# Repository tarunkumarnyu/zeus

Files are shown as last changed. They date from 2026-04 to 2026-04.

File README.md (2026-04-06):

# ZEUS — Autonomous Payload-Delivery Hexacopter






> **Note —** This is an **aero design project**, not a software repository. There is no source code: the work covers conceptual design, weight & thrust budgeting, propulsion sizing, structural analysis, CAD, and the build itself. This repo holds the SolidWorks assets, the system architecture, and the engineering drawing produced for the design report.

A custom-built hexacopter for autonomous waypoint missions with a 900 g servo-actuated payload drop. Designed and built by **Team ASRL** at SRM Institute of Science and Technology for **Rotorcraft Design Challenge — Nitte 2024**, the annual collegiate aero-design competition organised by **NMAM Institute of Technology** under the **SAE India Aerospace** banner (Team No. ROTOR2407).

## Contents

- [Conceptual Design](#conceptual-design)
- [Weight Estimation](#weight-estimation)
- [Thrust Estimation](#thrust-estimation)
- [Propulsion System](#propulsion-system)
- [UAV Configuration Selection](#uav-configuration-selection)
- [Wheelbase & Sizing](#wheelbase--sizing)
- [Power & Endurance](#power--endurance)
- [Design Iterations](#design-iterations)
- [Material Selection](#material-selection)
- [Subsystem Selection](#subsystem-selection)
- [System Architecture](#system-architecture)
- [CG, Topology Optimisation & FEA](#cg-topology-optimisation--fea)
- [Landing Gear](#landing-gear)
- [Autonomous Mission](#autonomous-mission)
- [Payload Drop Mechanism](#payload-drop-mechanism)
- [Weight Breakdown](#weight-breakdown)
- [Bill of Materials](#bill-of-materials)
- [Engineering Drawing](#engineering-drawing)

## Conceptual Design

<p align="center">
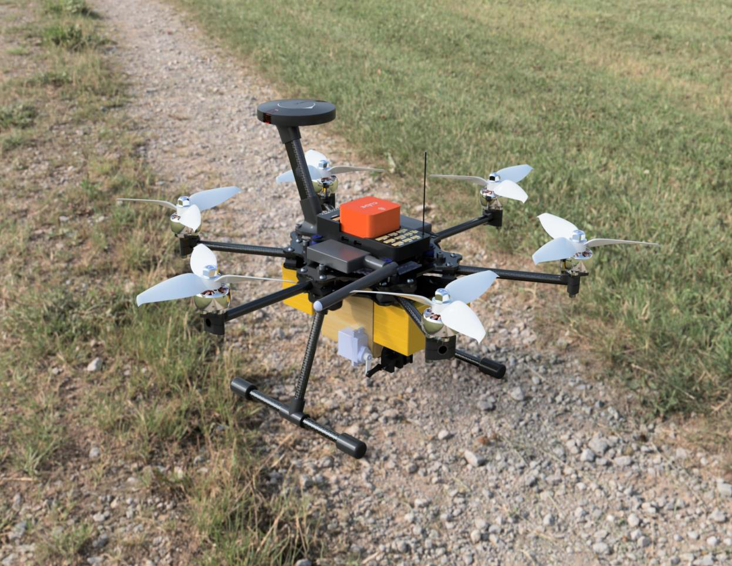
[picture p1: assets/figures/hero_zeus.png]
ZEUS hexacopter — high level view
  
  <br/><em>Fig. 1 — High level view of the assembled ZEUS platform</em>
</p>

ZEUS is a 2 kg-class hexacopter engineered for autonomous flight with precision payload delivery. The platform integrates a topology-optimised carbon-fiber airframe, a Pixhawk-based avionics stack, and a torque-balanced double-door payload bay. The full mission — take-off, GPS waypoint navigation, target loiter, payload release, return-to-home — is planned in Mission Planner and executed autonomously by the flight controller.

The hexacopter configuration was chosen over a quadcopter for the 50% thrust margin and motor-failure tolerance, and over an octocopter to keep weight and current draw low enough to fit a 5+ minute flight envelope on a single 6S battery pack.

## Weight Estimation

Take-off weight is estimated using the standard rotorcraft formula:

```
Wto = Woe + Wpl + Wf
```

| Term | Description | Value |
|---|---|---|
| `Woe` | Operational empty weight (frame + electronics, no battery) | 671 g |
| `Wpl` | Payload weight (mission requirement) | 900 g |
| `Wf`  | "Fuel" weight — battery pack | 480 g |
| **`Wto`** | **Total take-off weight** | **2051 g** |

Preliminary estimate during early design was 2120 g; the final figure of **2051 g** reflects a 69 g reduction achieved through frame iteration and topology optimisation.

## Thrust Estimation

```
Thrust required for take-off = Wto + 20% safety margin
                             = 2051 + 410.2 = 2461.2 g

Thrust per motor             = 2461.2 / 6 = 410.2 g
```

A 20% margin above hover ensures sufficient authority for climb, manoeuvring, and gust rejection. The selected motor/prop combination delivers >430 g per motor at the operating voltage, clearing the requirement.

## Propulsion System

An electric propulsion system was chosen for low noise, zero local emissions, and compatibility with the small-frame BLDC ecosystem.

| Item | Selection | Rationale |
|---|---|---|
| Motors | **Emax ECO II 2306, 1700 KV BLDC** | Meets 410 g/motor static thrust target; high durability; low electrical noise |
| Propellers | **5″ tri-blade** | Best stability/efficiency trade for the wheelbase; tri-blade preferred over bi-blade for thrust at this disc loading |
| Battery | **2× 1300 mAh 6S LiPo (parallel)** | 2600 mAh, 25.2 V nominal, 100C discharge — supports peak current and 5 min endurance |

<table align="center">
<tr>
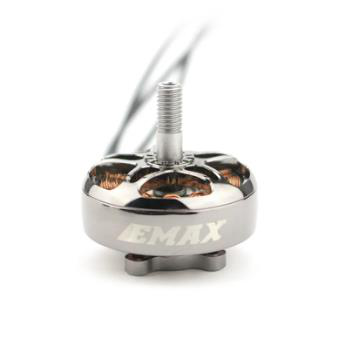
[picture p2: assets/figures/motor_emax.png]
<td align="center"><br/><em>Fig. 2 — Emax ECO II 2306 BLDC motor</em></td>
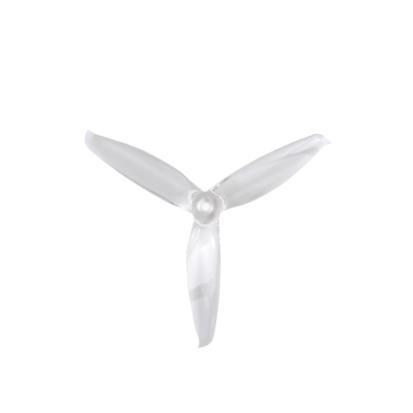
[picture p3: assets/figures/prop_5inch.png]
<td align="center"><br/><em>Fig. 3 — 5″ tri-blade propeller</em></td>
</tr>
</table>

## UAV Configuration Selection

| Configuration | Weight | Endurance | Stability | Thrust |
|---|---|---|---|---|
| Quadcopter | Low | High | Low | Low |
| **Hexacopter** | **Medium** | **Medium** | **High** | **High** |
| Octocopter | High | Low | High | High |

**Why hexacopter:** Two extra motors over a quadcopter increase total static thrust by 50%, reduce per-motor load and current draw, and provide tolerance to a single-motor failure (the controller can compensate by re-mixing the remaining five). An octocopter would add weight and current draw without a meaningful payload-fraction gain at this scale.

<table align="center">
<tr>
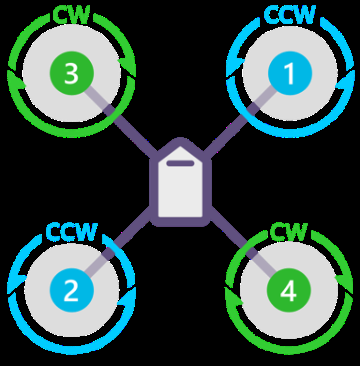
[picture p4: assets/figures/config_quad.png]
<td align="center"><br/><em>Fig. 4 — X Quad</em></td>
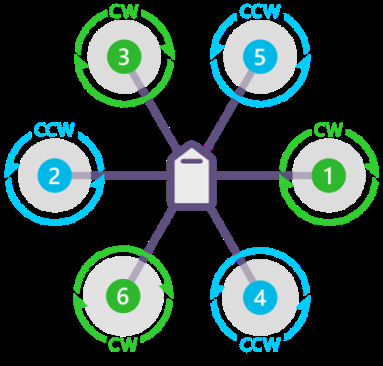
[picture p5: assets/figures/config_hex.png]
<td align="center"><br/><em>Fig. 5 — X Hexa (selected)</em></td>
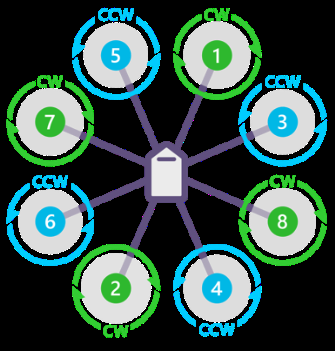
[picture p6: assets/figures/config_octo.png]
<td align="center"><br/><em>Fig. 6 — X Octo</em></td>
</tr>
</table>

## Wheelbase & Sizing

- **Horizontal wheelbase** (centre to centre, adjacent motor mount): **168 mm**
- **Diagonal wheelbase** (motor to opposite motor): **335 mm**
- **Propeller clearance**: **40 mm** between adjacent prop tips to prevent collisions
- **Overall envelope**: L = 335.5 mm, W = 290.5 mm, H = 237.6 mm
- **Landing gear height**: 100 mm — sufficient ground clearance for payload bay attachment without ground strike

All electronics live on the top plate for CG balance and easy field access. The two batteries sit symmetrically front and rear at datum distances of 89 mm and 199 mm so the loaded CG stays within ±5 mm of the geometric centre.

<table align="center">
<tr>
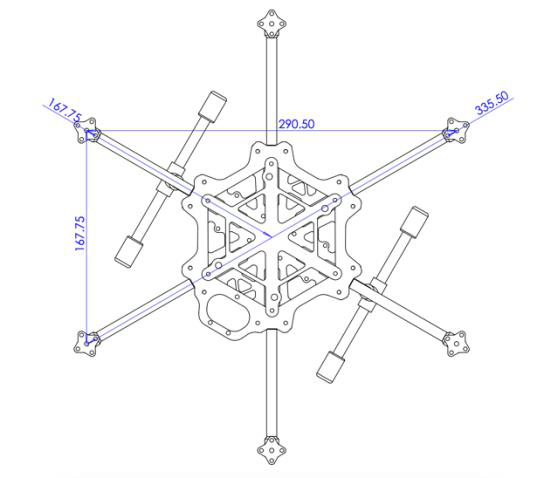
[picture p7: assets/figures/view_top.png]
<td align="center"><br/><em>Fig. 7 — Wheelbase &amp; top view dimensions</em></td>
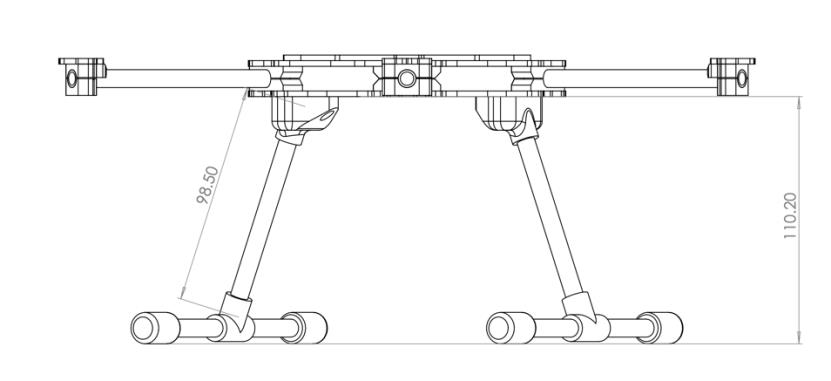
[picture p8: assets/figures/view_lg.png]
<td align="center"><br/><em>Fig. 8 — Front view with landing-gear clearance</em></td>
</tr>
</table>

## Power & Endurance

**Power required (hover):**

```
Hover current per motor : 4 A
Bus voltage             : 25.2 V
Power per motor         : 100.8 W
Power for 6 motors      : 604.8 W
Avionics overhead       : ~20 W
Total hover power       : 625 W
```

**Power available:**

```
Battery energy = 2.6 Ah × 25.2 V = 65.52 Wh
Energy for 5 min hover = 625 W × (5/60) h = 51.875 Wh   ✓ (margin of 13.6 Wh)
```

**Endurance:**

```
Avg amp draw = (Wto · 294.811 W/kg) / 25.2 V
             = (2.051 · 294.811) / 25.2
             = 23.99 A

Flight time @ 80% safe discharge = (2.6 · 0.8) / 23.99
                                 = 0.0867 h
                                 ≈ 5.20 min
```

The 80% discharge limit is enforced to preserve LiPo cell health.

## Design Iterations

The frame went through three major iterations, each driven by FEA results and weight measurements from the previous build.

**Iteration 1 — Strength-first.**
Designed to withstand extreme combined loads. Base plate topology-optimised with 10% material removal. 15 mm CF round tubes used as arms. Motor mount plates fixed with two dual-arm attachments per arm for maximum stiffness. **Drawback:** excessive weight from the heavy tubes and large fastener count.

**Iteration 2 — Weight reduction.**
Aggressive topology optimisation on every plate. 15 mm CF round tubes replaced with **pultruded CF square tubes** (lighter, easier to clamp). Motor mount bolts cut from **9 to 2 per motor**. Significant weight savings, but the square pultruded tubes were not as strong as desired in bending.

**Final Iteration — Stability + strength.**
Distance between base and top plate **minimised** to maximise frame torsional stiffness. Pultruded square tubes replaced with **8 mm circular 3K roll-wrapped CF tubes** — lighter per arm and significantly stronger than pultruded due to the continuous fibre wrap. This is the version that flew.

<table align="center">
<tr>
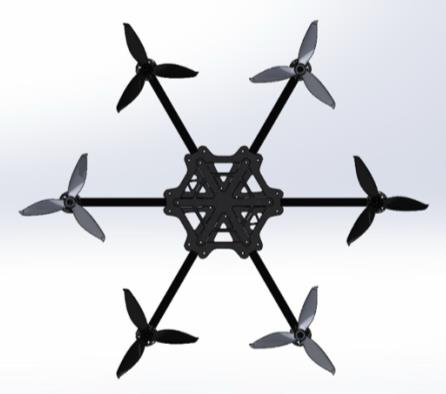
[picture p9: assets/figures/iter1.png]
<td align="center"><br/><em>Fig. 9 — Iteration 1 (strength-first)</em></td>
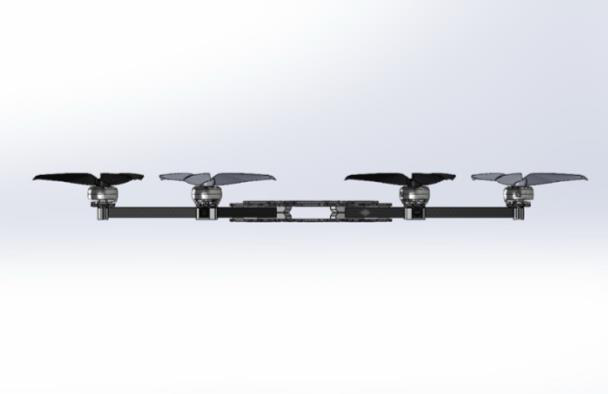
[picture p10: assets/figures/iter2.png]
<td align="center"><br/><em>Fig. 10 — Iteration 2 (weight reduction)</em></td>
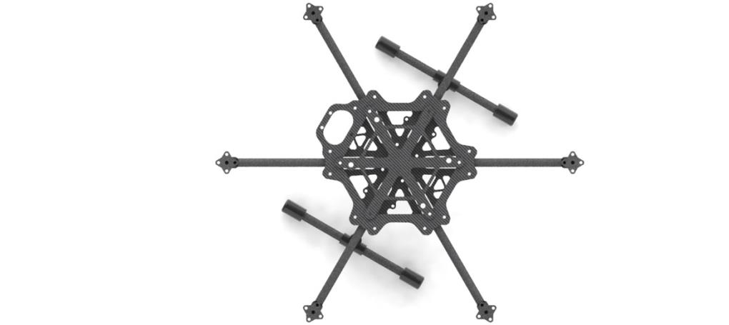
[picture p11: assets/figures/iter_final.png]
<td align="center"><br/><em>Fig. 11 — Final iteration</em></td>
</tr>
</table>

## Material Selection

**Carbon-Fiber Plate (frame plates).** High strength-to-weight ratio carries flight loads with minimal mass. Rigid under combined thrust and gust loads, preventing flex that would otherwise corrupt IMU readings.

**3K Roll-Wrapped CF Tube (arms).** Continuous-fibre wrapped tubes selected over pultruded because the fibre orientation gives excellent bending and torsional stiffness — essential for arms that carry the full thrust moment of one motor at the tip.

**PLA+ (3D-printed attachments).** All complex geometric attachments — motor mounts, arm clamps, payload bay parts, landing gear feet — manufactured via FDM 3D printing in PLA+. Higher toughness and inter-layer adhesion than standard PLA, no warping issues during long prints.

<p align="center">
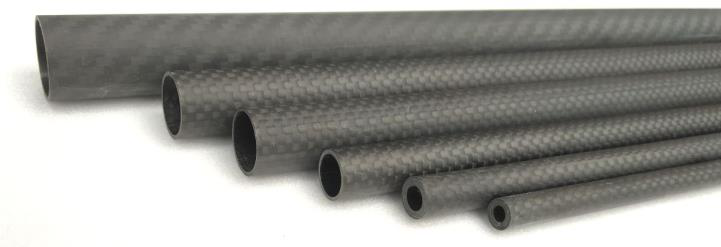
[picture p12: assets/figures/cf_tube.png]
3K roll-wrapped CF tubes
  
  <br/><em>Fig. 12 — 3K roll-wrapped carbon-fiber tube stock used for the arms</em>
</p>

## Subsystem Selection

### Telemetry
**Holybro SiK Telemetry Module.** MAVLink-compatible, plug-and-play with Mission Planner. 433 MHz, 500 mW output. Used for live mission upload, parameter tuning in the field, and downlink of GPS / battery / attitude.

<p align="center">
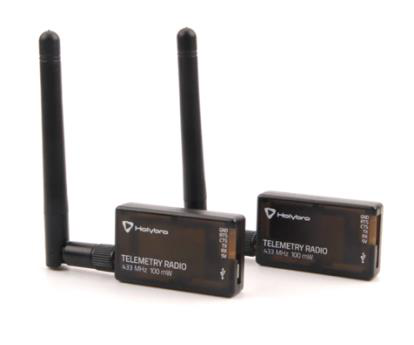
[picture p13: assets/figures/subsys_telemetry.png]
Holybro SiK telemetry module
  
  <br/><em>Fig. 13 — Holybro telemetry SiK module pair</em>
</p>

### Radio link
**TBS Tango 2 Pro + Crossfire receiver.** Crossfire protocol on 915 MHz, 4 km range, 8 channels — 4 for axes (roll, pitch, yaw, throttle) and 4 for flight mode switching, payload trigger, and arm/disarm.

<p align="center">
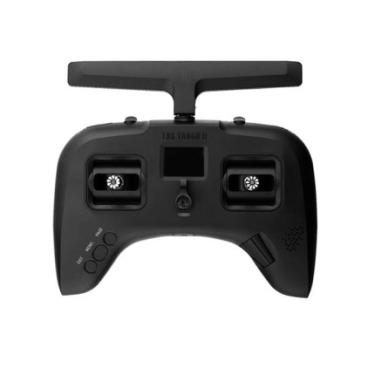
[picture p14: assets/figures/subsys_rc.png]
TBS Tango 2 Pro transmitter
  
  <br/><em>Fig. 14 — TBS Tango 2 Pro transmitter</em>
</p>

### Flight controller
**Pixhawk Cube Orange.**
- 3 sets of IMU sensors with redundancy voting
- 2 of the 3 IMUs are vibration-isolated for accurate state estimation
- Onboard heater resistors hold IMU temperature stable to reduce gyro bias drift
- Runs ArduPilot with the standard hexacopter mixer

<p align="center">
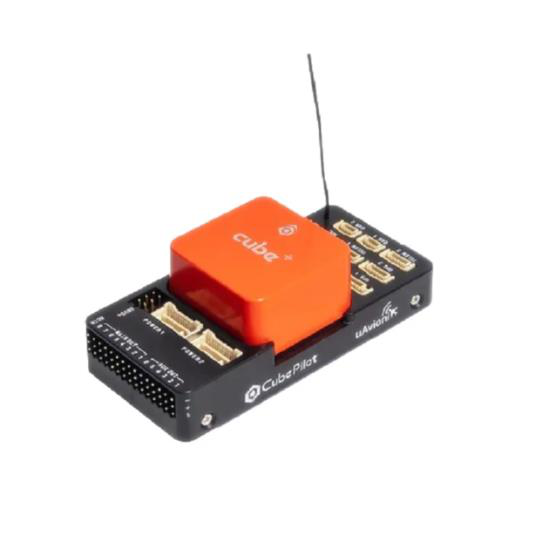
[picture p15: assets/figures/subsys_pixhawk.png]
Pixhawk Cube Orange
  
  <br/><em>Fig. 15 — Pixhawk Cube Orange flight controller</em>
</p>

### GPS / INS
**Here3 GPS.** Full inertial navigation suite — gyroscope, accelerometer, magnetometer, barometer — combined with GNSS receiver. RTK positioning data is fused with IMU/baro in the Pixhawk's Extended Kalman Filter (EKF) for sub-metre position hold.

<p align="center">
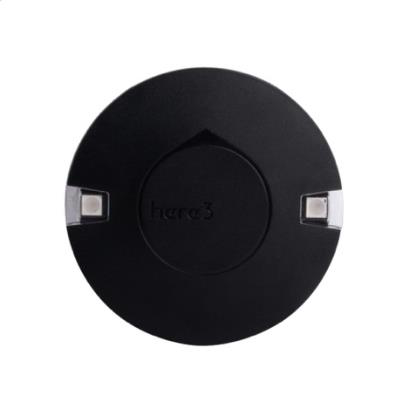
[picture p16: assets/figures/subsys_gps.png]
Here3 GPS
  
  <br/><em>Fig. 16 — Here3 RTK GPS / INS unit</em>
</p>

### Electronic Speed Controllers
Two **4-in-1 ESC modules** chosen instead of six individual ESCs to save weight, wiring complexity, and assembly time. Specifications:
- 3S–6S input range
- 50 A continuous per channel
- 1000 µF bulk capacitor per ESC to filter PWM-induced current ripple at the battery bus

<table align="center">
<tr>
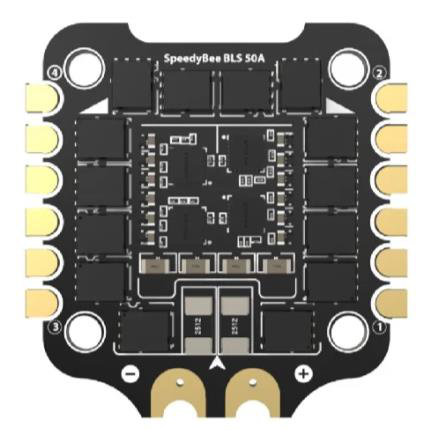
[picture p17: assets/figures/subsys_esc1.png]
<td align="center"><br/><em>Fig. 17 — Speedybee 50 A 4-in-1 ESC</em></td>
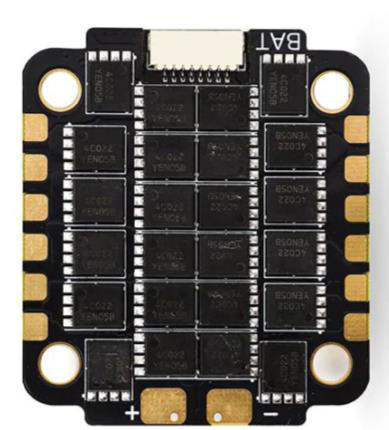
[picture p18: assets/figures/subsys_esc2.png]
<td align="center"><br/><em>Fig. 18 — HGLRC 50 A 4-in-1 ESC</em></td>
</tr>
</table>

## System Architecture

<p align="center">
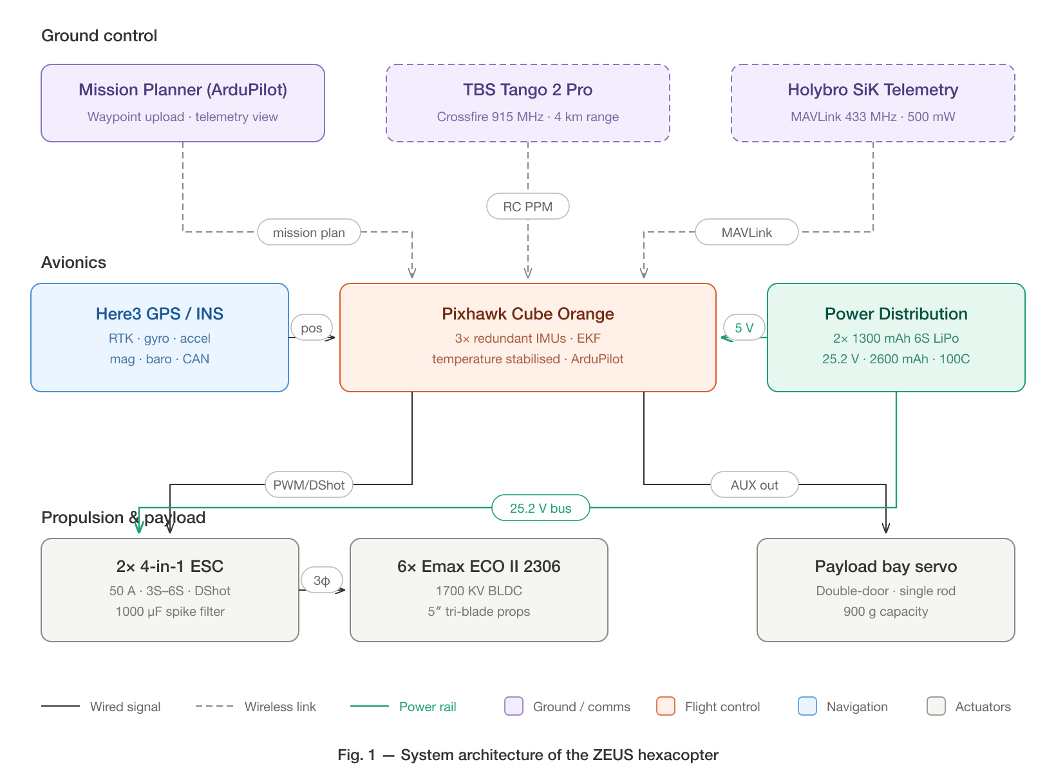
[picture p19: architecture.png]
ZEUS System Architecture
  
</p>

## CG, Topology Optimisation & FEA

**CG estimation.** Two battery slots are placed symmetrically front and back of the frame. The loaded CG falls almost exactly at the midpoint of the two battery slots and slightly above the geometric origin of the airframe — close enough to the thrust centroid that no asymmetric trim is required.

<p align="center">
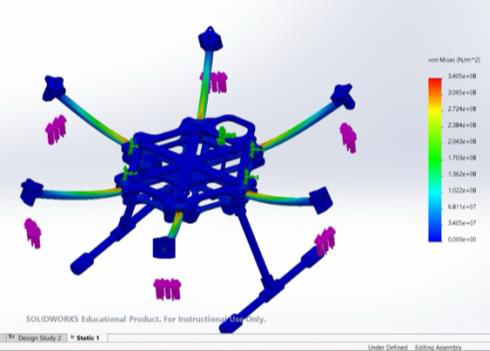
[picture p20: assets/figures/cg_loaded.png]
Loaded CG render
  
  <br/><em>Fig. 20 — Loaded CG: ZEUS with payload bay attached, front view</em>
</p>

**Topology optimisation.** Two FEA load cases were run on the base plate:
- *Method 1* — fixtures at the arm mountings, force applied at the plate centre (simulating a payload load on a hovering frame)
- *Method 2* — centre of plate fixed, force applied at the arm mountings (simulating thrust loads in flight)

The final geometry is the **intersection** of the load paths from both methods — material is removed only where neither case carries stress.

<table align="center">
<tr>
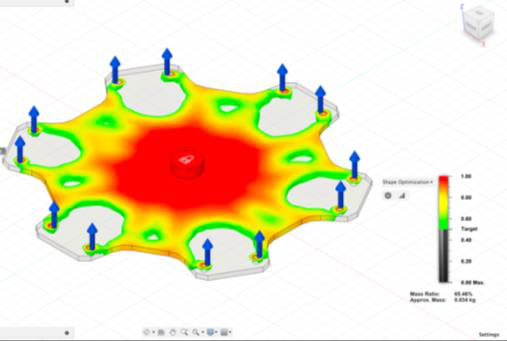
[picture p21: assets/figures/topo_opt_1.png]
<td align="center"><br/><em>Fig. 21 — Topology optimisation, Method 1</em></td>
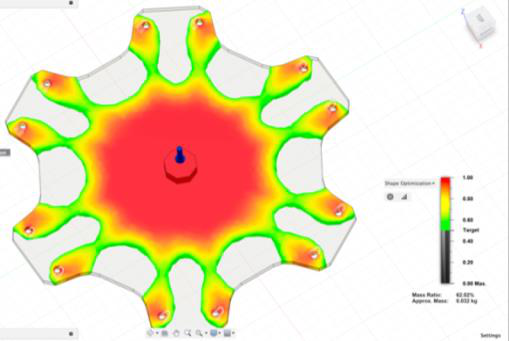
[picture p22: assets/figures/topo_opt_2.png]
<td align="center"><br/><em>Fig. 22 — Topology optimisation, Method 2</em></td>
</tr>
</table>

**Static structural analysis.** Whole-frame FEA was run under the maximum combined static thrust of all six motors (~120 N) to validate plate integrity under the worst-case flight load. Maximum von Mises stress stayed well below the CF laminate's yield, with peak displacement at the plate corners.

<table align="center">
<tr>
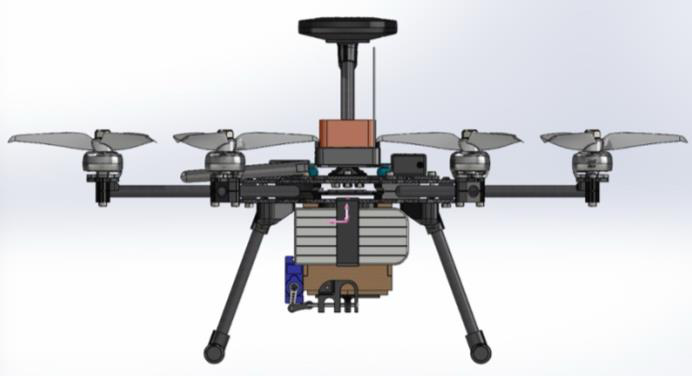
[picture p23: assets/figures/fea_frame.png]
<td align="center"><br/><em>Fig. 23 — Plate-level static FEA</em></td>
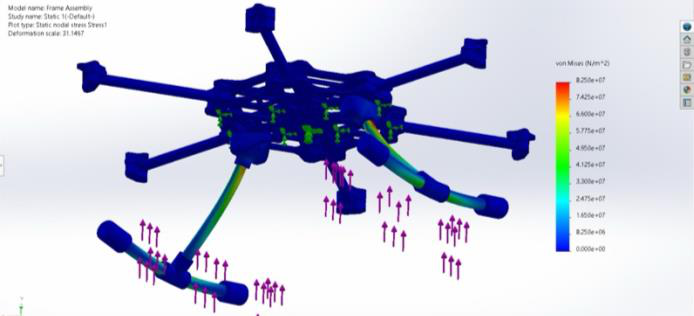
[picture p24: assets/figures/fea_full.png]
<td align="center"><br/><em>Fig. 24 — Full-frame static FEA under 120 N thrust</em></td>
</tr>
</table>

## Landing Gear

A **skid-type** landing gear was selected over wheeled or fixed-leg alternatives for maximum stability and ground contact area. The gear was designed in SolidWorks and run through FEA under the worst-case landing impact load to size the wall thickness. Complex skid geometry is **3D-printed in PLA+** with internal infill tuned to absorb impact energy without permanent deformation.

The 100 mm clearance is the minimum that lets the payload bay clear the ground when the bay doors are open.

<p align="center">
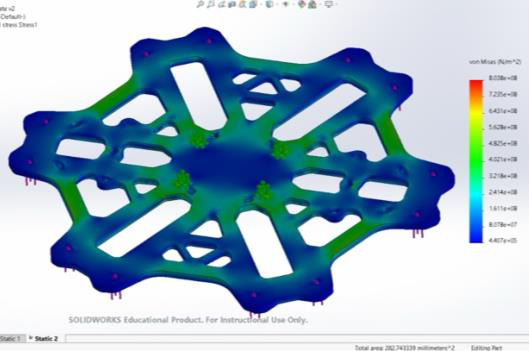
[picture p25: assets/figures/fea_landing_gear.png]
Landing gear FEA
  
  <br/><em>Fig. 25 — Landing gear FEA under landing impact load</em>
</p>

## Autonomous Mission

Mission planning is done in **Mission Planner (ArduPilot)**. The pilot defines the home position, take-off altitude, GPS waypoint sequence, and return-to-home behaviour; the full plan is uploaded to the Pixhawk over the 433 MHz MAVLink telemetry link before flight.

```
Arm + Take-off  →  Waypoint nav  →  Target loiter  →  Payload drop  →  Return to home
```

**Phase 1 — Take-off.** Take-off altitude is set to 5 m in the ground station. The Pixhawk arms, spools the motors, and climbs vertically to the set altitude under altitude-hold.

**Phase 2 — Waypoint Navigation.** The drone follows the planned GPS waypoint path autonomously between home and the target area. The EKF fuses RTK GPS with IMU and baro to maintain position lock.

**Phase 3 — Target Loiter & Drop.** The drone holds station above the target while the payload servo is triggered (via an AUX channel from the FC).

**Phase 4 — Return to Home.** On mission completion, the drone autonomously returns to the home position and performs a controlled descent.

<table align="center">
<tr>
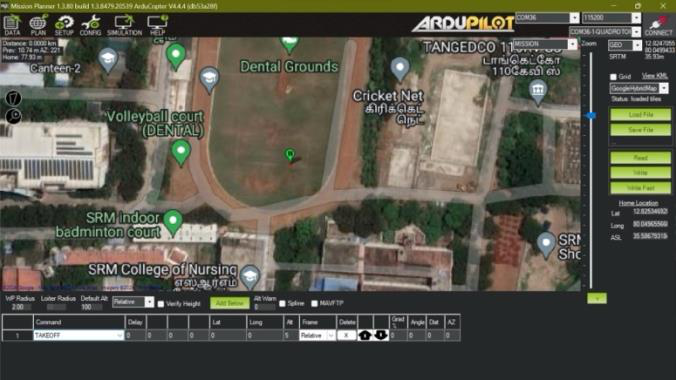
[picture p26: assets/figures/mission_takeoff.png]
<td align="center"><br/><em>Fig. 26 — Mission Planner: take-off altitude set</em></td>
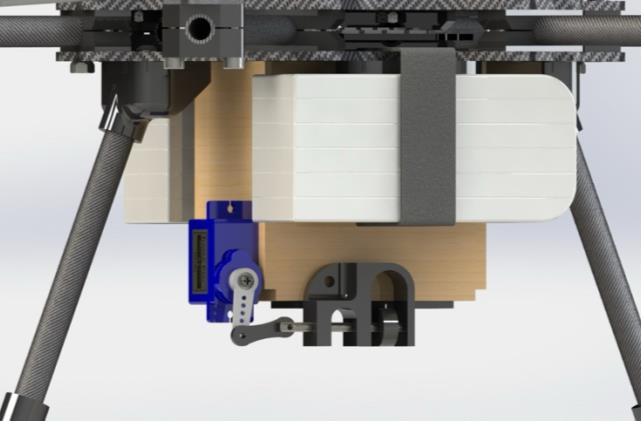
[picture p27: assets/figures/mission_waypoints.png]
<td align="center"><br/><em>Fig. 27 — Mission Planner: waypoint plan</em></td>
</tr>
</table>

## Payload Drop Mechanism

The payload bay sits below the frame on a **double-door release mechanism** actuated by a single servo. Key design choices:

- **Double-door geometry** — two symmetric doors open simultaneously instead of a single side door. This cancels the reaction torque at release so the drop does not perturb the airframe's attitude.
- **Single-rod lock** — a single sliding rod, driven by one servo, latches both doors. This minimises the part count and the failure modes.
- **900 g rated capacity** — sized to the competition payload spec.
- **Mounted below the airframe** on the centreline so the CG shift after release is purely vertical.

<table align="center">
<tr>
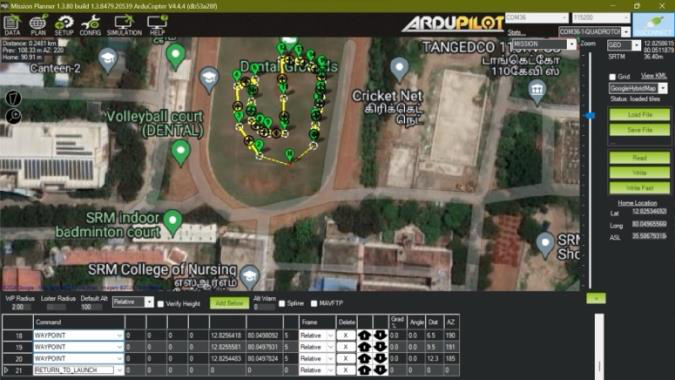
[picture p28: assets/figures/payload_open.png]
<td align="center"><br/><em>Fig. 28 — Payload bay (doors closed, latched)</em></td>
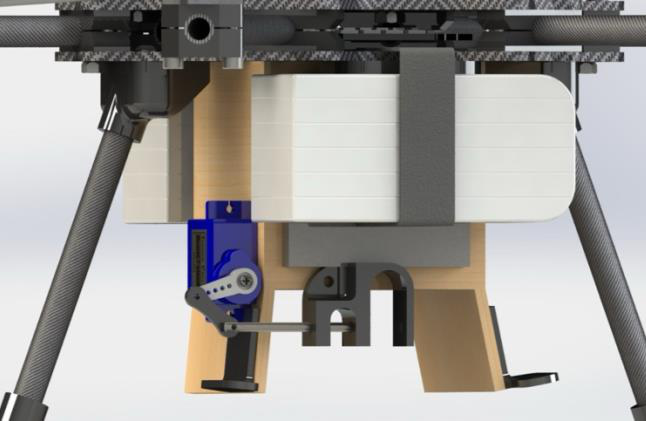
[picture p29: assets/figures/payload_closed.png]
<td align="center"><br/><em>Fig. 29 — Payload bay (servo + lock rod detail)</em></td>
</tr>
</table>

## Weight Breakdown

### Electronics

| Component | Unit (g) | Qty | Total (g) |
|---|---|---|---|
| BLDC motors | 30.4 | 6 | 182.4 |
| Battery (6S 1300 mAh) | 230 | 2 | 460 |
| 4-in-1 ESC | 18 | 2 | 36 |
| Here3 GPS | 48.8 | 1 | 48.8 |
| Pixhawk Cube Orange | 73 | 1 | 73 |
| Holybro Telemetry | 15 | 1 | 15 |
| Crossfire receiver | 2 | 1 | 2 |
| Power module | 14 | 1 | 14 |
| Propellers | 6.8 | 6 | 40.8 |
| Servo motor (payload) | 9 | 1 | 9 |
| **Subtotal** | | | **881 g** |

### Frame

| Component | Unit (g) | Qty | Total (g) |
|---|---|---|---|
| Base plate | 46.23 | 1 | 46.23 |
| Top plate | 28.48 | 1 | 28.48 |
| FC plate | 19.81 | 1 | 19.81 |
| Arm tube | 4.83 | 6 | 28.98 |
| Motor mount plate | 1.08 | 6 | 6.48 |
| LG vertical | 4.39 | 2 | 8.78 |
| LG horizontal | 6.59 | 2 | 13.18 |
| M3 × 20 mm bolt | 1.60 | 24 | 38.4 |
| M3 × 8 mm bolt | 1.10 | 6 | 6.6 |
| LG-to-base mount | 6.5 | 2 | 13 |
| LG damper | 1 | 4 | 4 |
| Arm mount | 1.5 | 12 | 18 |
| MM attachment | 1 | 12 | 12 |
| T attachment | 2 | 2 | 4 |
| **Subtotal** | | | **247.94 g** |

## Bill of Materials

| Component | Unit (₹) | Qty | Total (₹) |
|---|---|---|---|
| BLDC motor | 1,465 | 6 | 8,790 |
| 6S 1300 mAh LiPo | 2,499 | 2 | 4,998 |
| 4-in-1 ESC | 4,049 | 2 | 8,098 |
| Here3 GPS | 18,093 | 1 | 18,093 |
| Pixhawk Cube Orange | 32,999 | 1 | 32,999 |
| Holybro Telemetry | 7,563 | 1 | 7,563 |
| TBS Tango 2 + Crossfire Rx | 26,378 | 1 | 26,378 |
| Propellers | 179 | 2 | 358 |
| Servo motor | 97 | 1 | 97 |
| CF plate (2.5 mm) | 4,308 | 1 | 4,308 |
| CF tube (8 mm) | 649 | 3 | 1,947 |
| PLA+ filament | 999 | 1 | 999 |
| **Total** | | | **₹1,14,628** |

## Engineering Drawing

Final dimensioned drawing from the design report — front, right, top, and isometric views with weight & balance summary.

<p align="center">
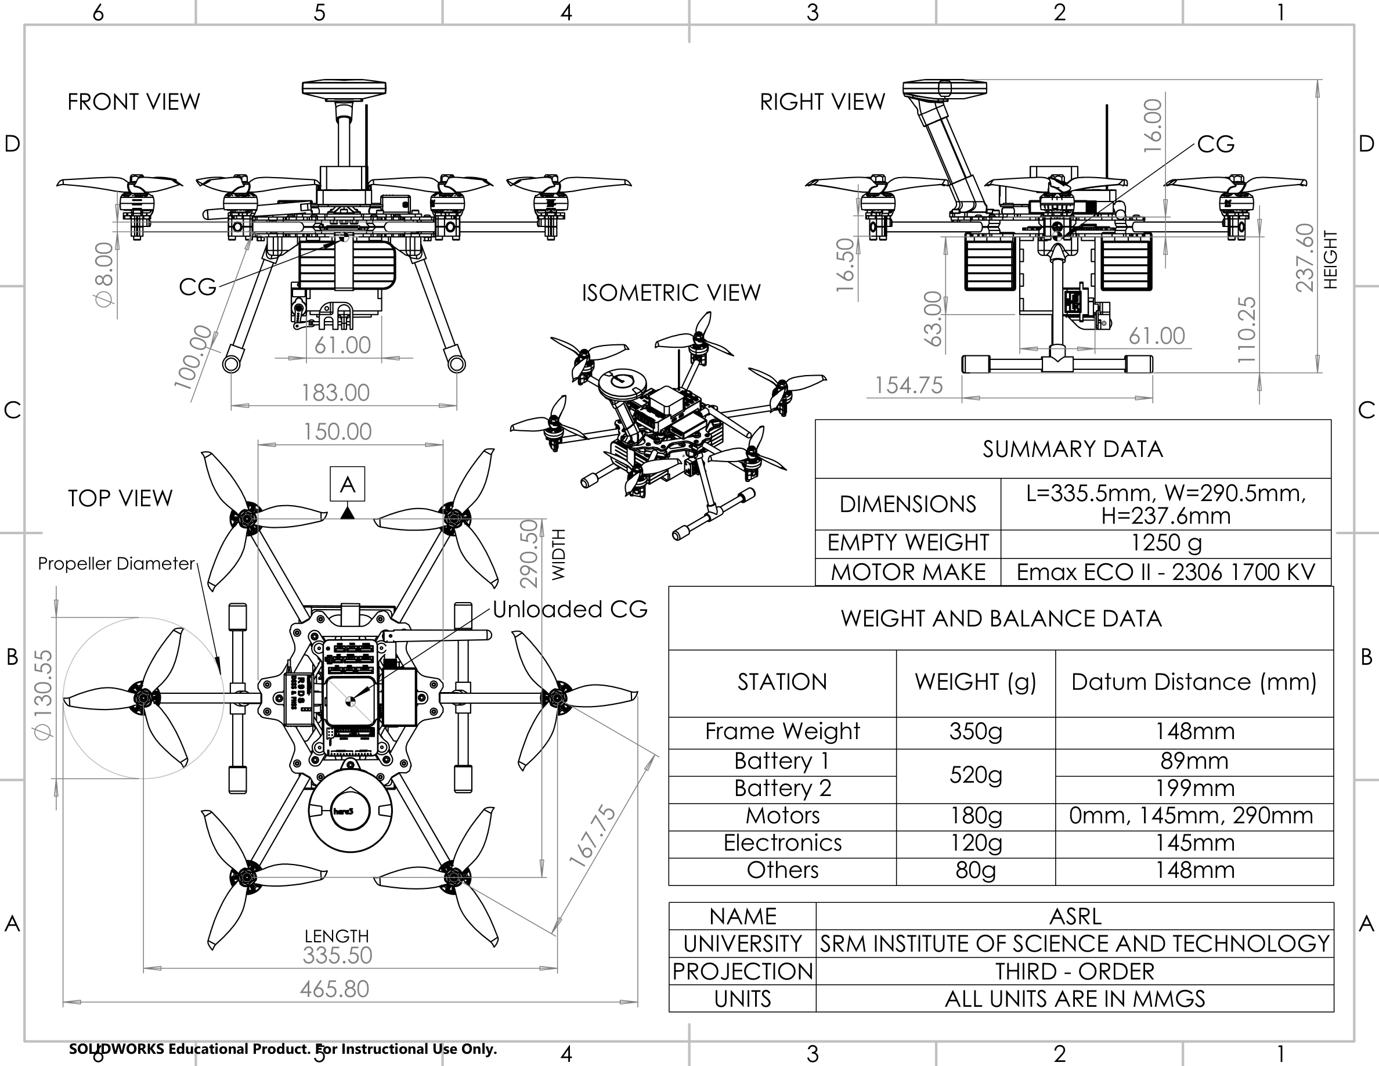
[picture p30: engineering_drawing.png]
ZEUS engineering drawing — front, right, top, isometric views with weight & balance
  
</p>

| Parameter | Value |
|---|---|
| Length × Width × Height | 335.5 × 290.5 × 237.6 mm |
| Empty weight | 1250 g |
| Motor | Emax ECO II 2306, 1700 KV |
| Propeller diameter | 130.55 mm (5″) |
| Landing gear clearance | 100 mm |

**Weight & balance stations** (datum at frame nose):

| Station | Weight (g) | Datum distance (mm) |
|---|---|---|
| Frame | 350 | 148 |
| Battery 1 | 520 | 89 |
| Battery 2 | 520 | 199 |
| Motors | 180 | 0 / 145 / 290 |
| Electronics | 120 | 145 |
| Other | 80 | 148 |

## Repository Layout

```
zeus/
├── cad/                     # SolidWorks parts, assemblies, and rendering setups
├── assets/figures/          # Figures from the design report
├── architecture.svg         # System architecture diagram (vector)
├── architecture.png         # Rendered architecture diagram
├── engineering_drawing.png  # Final dimensioned drawing (4-view + W&B)
└── README.md
```

## Stack

`ArduPilot` · `Mission Planner` · `Pixhawk Cube Orange` · `Here3 RTK GPS` · `MAVLink` · `Crossfire` · `SolidWorks` · `FEA` · `Topology Optimisation` · `Carbon Fiber` · `PLA+`

## Team

**Team ASRL — SRM Institute of Science and Technology**
P. Tarun Kumar · Raghunath VM · Adarsh Jha · Manan Wadhwa · Rhythm Pareek · Muhammed Sahal M N · Vijay Solanki · Akshika Pathania

## License

This project is licensed under the [MIT License](LICENSE).

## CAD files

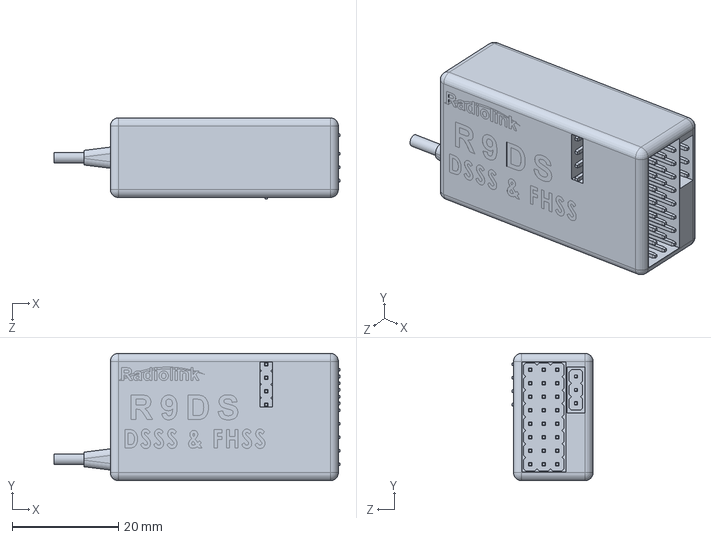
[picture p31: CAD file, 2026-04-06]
cad/R9DS RadioLink Receiver Assy.SLDPRT
53.9 x 24.0 x 15.3 mm

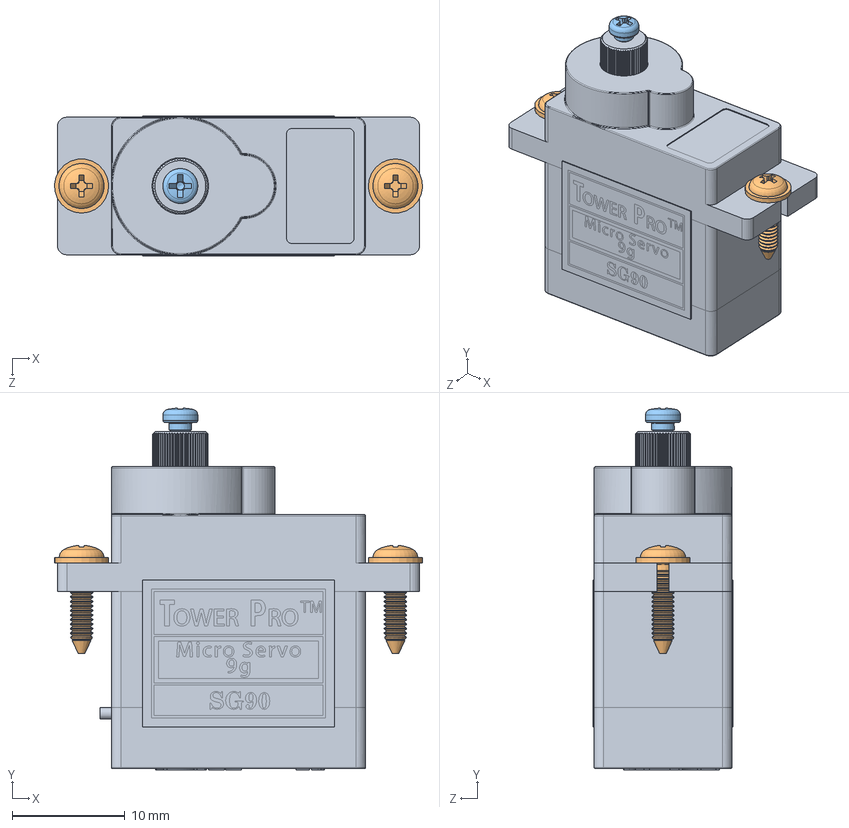
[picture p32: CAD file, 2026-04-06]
cad/SG90 - Micro Servo 9g - Tower Pro.SLDASM
32.6 x 32.0 x 12.4 mm
SG90 - Micro Servo 9g - Tower Pro.1
SG90 - Micro Servo 9g - Tower Pro.5 x 2
SG90 - Micro Servo 9g - Tower Pro.6

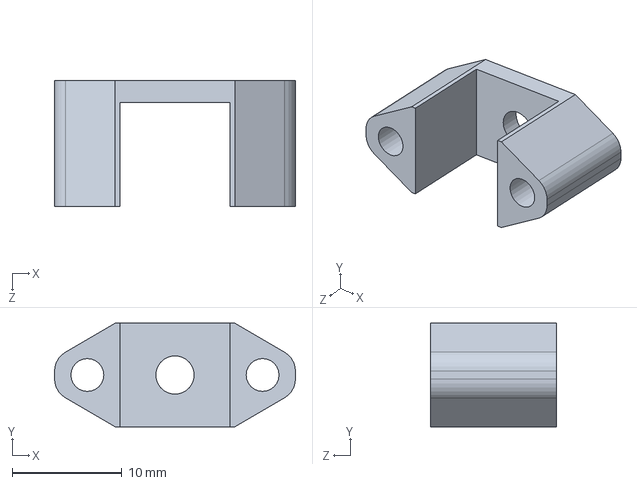
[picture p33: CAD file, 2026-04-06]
cad/mm plate attach v2.SLDPRT
22.0 x 9.47 x 11.5 mm

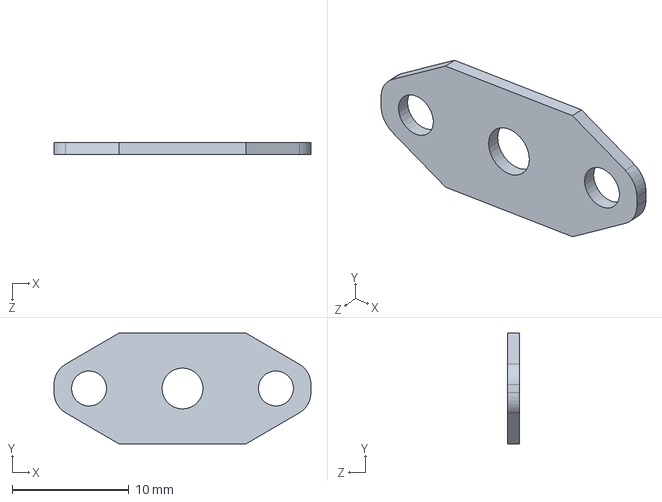
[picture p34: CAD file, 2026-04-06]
cad/mm plate attach top.SLDPRT
22.0 x 9.47 x 1.00 mm

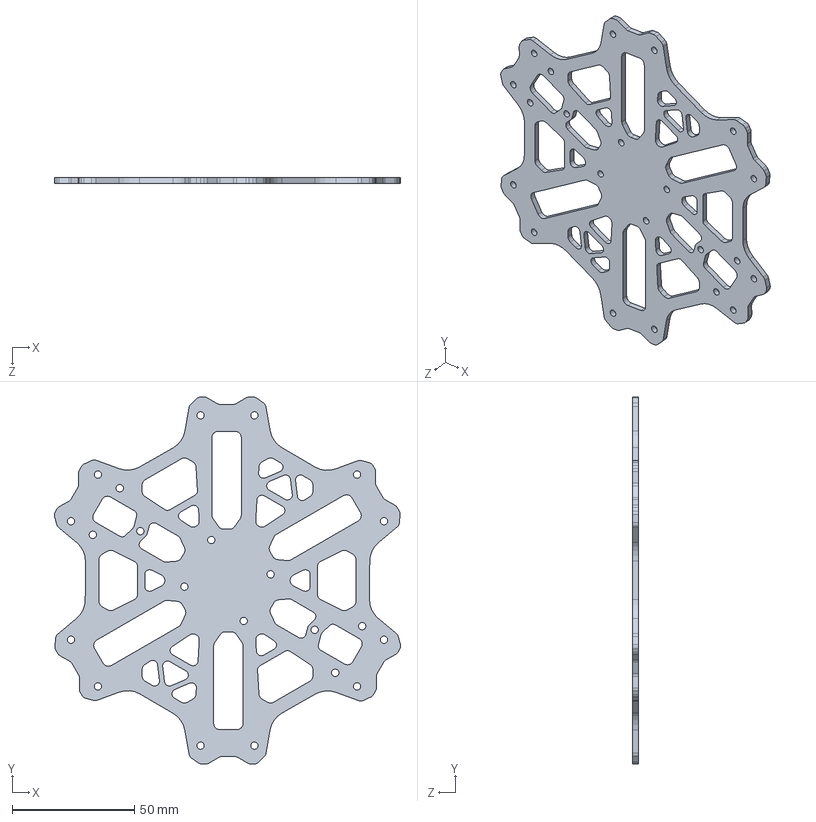
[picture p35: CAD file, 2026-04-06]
cad/base plate v2.SLDPRT
141.5 x 150.0 x 2.50 mm

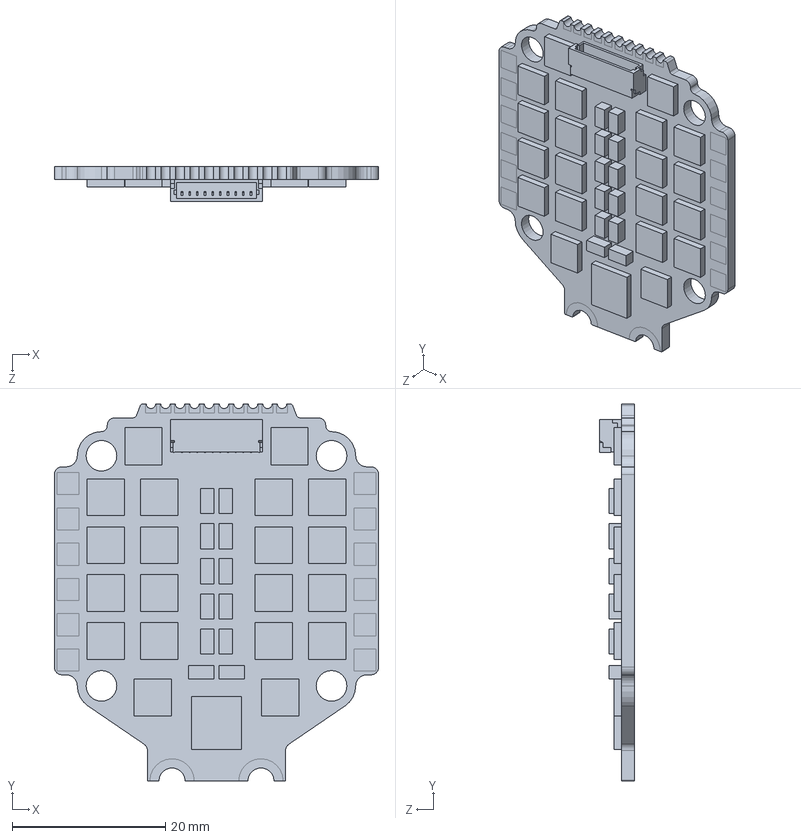
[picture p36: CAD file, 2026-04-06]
cad/esc.SLDPRT
42.3 x 49.1 x 4.60 mm

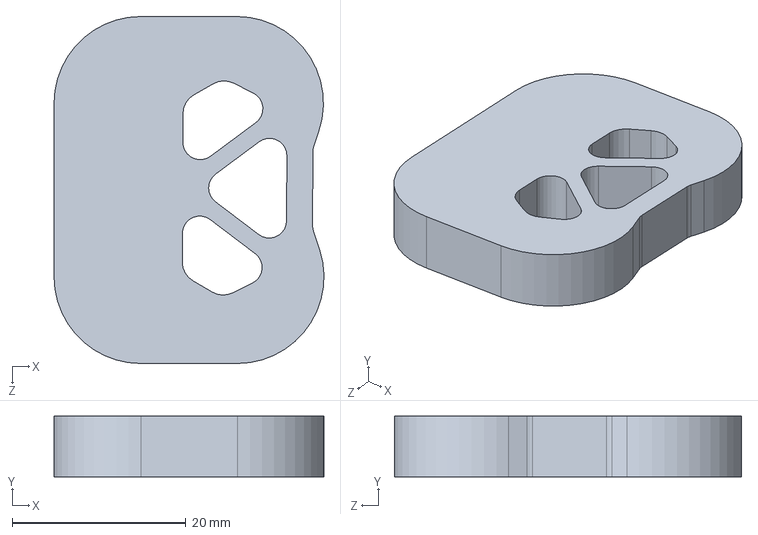
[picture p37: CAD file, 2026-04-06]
cad/battery spacer.SLDPRT
31.1 x 7.00 x 40.0 mm

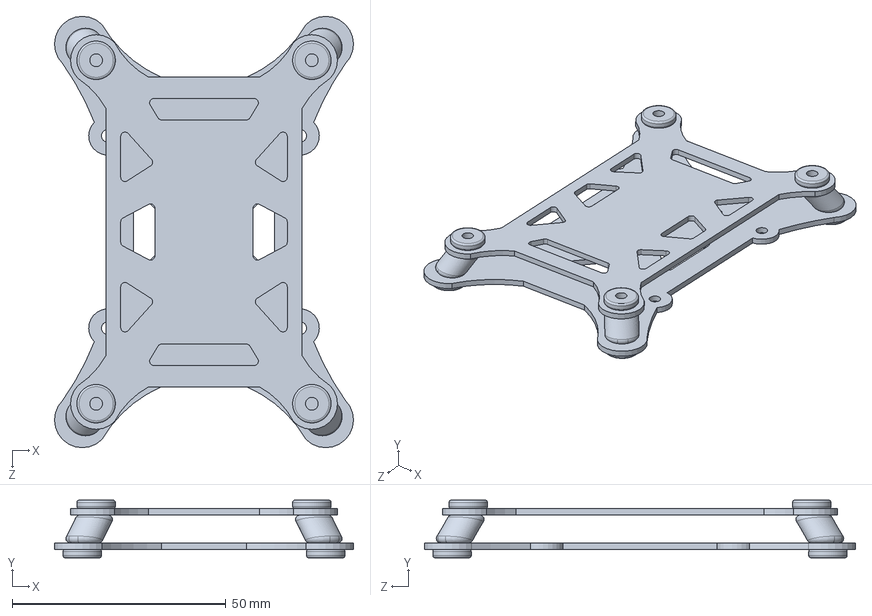
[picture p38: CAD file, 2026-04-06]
cad/base_pixhawk.SLDPRT
70.0 x 13.5 x 101.0 mm

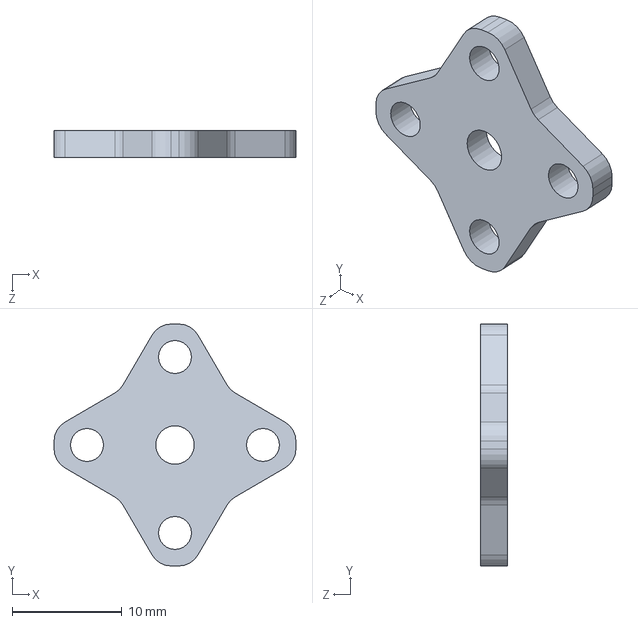
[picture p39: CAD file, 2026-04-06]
cad/mm plate v2.SLDPRT
22.0 x 22.0 x 2.50 mm

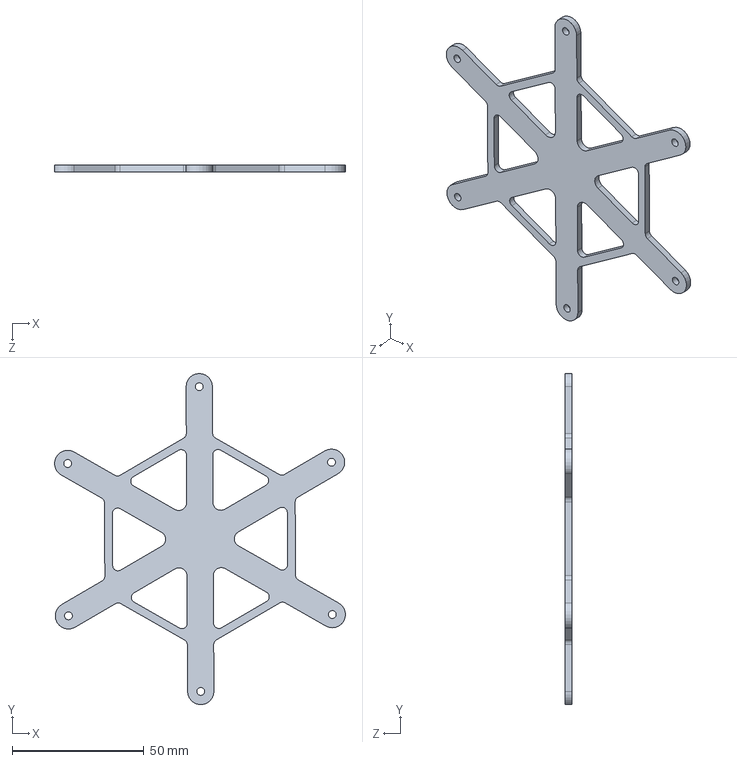
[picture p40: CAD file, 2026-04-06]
cad/pixhawk plate.SLDPRT
110.3 x 125.4 x 2.50 mm

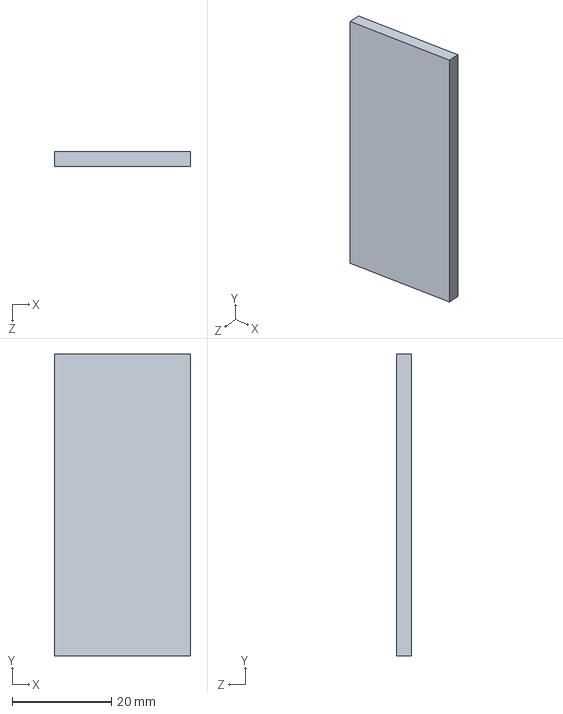
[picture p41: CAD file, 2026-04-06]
cad/payload door.SLDPRT
27.5 x 61.0 x 3.00 mm

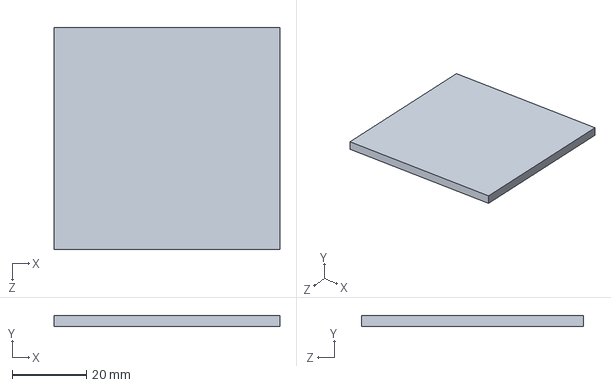
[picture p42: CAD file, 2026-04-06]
cad/payload l1.SLDPRT
61.0 x 3.00 x 60.0 mm

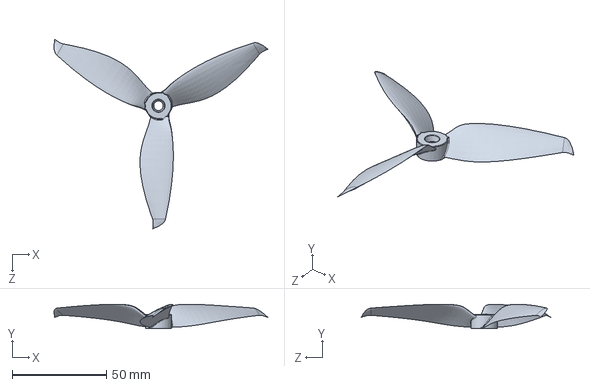
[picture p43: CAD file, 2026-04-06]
cad/GEMFAN_5152_CCW.SLDPRT
113.3 x 12.9 x 100.5 mm

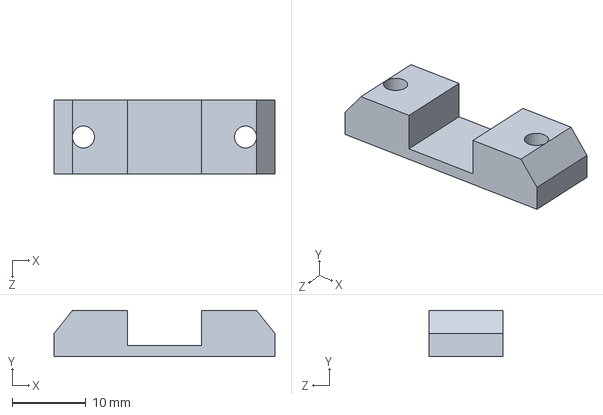
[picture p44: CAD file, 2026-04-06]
cad/arm mount v2.SLDPRT
30.0 x 6.25 x 10.0 mm

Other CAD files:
cad/Telemetry Holybro Assembly.SLDASM
cad/Payload assem.SLDASM
cad/Here3.SLDPRT
cad/GEMFAN_5152_CW.SLDPRT
cad/Antenna 1.SLDPRT
cad/Antenna 2.SLDPRT
cad/Arm Tube.SLDPRT
cad/Here3_Istand.SLDPRT
cad/SG90 - Micro Servo 9g - Tower Pro.1.SLDPRT
cad/SG90 - Micro Servo 9g - Tower Pro.2.SLDPRT
cad/SG90 - Micro Servo 9g - Tower Pro.3.SLDPRT
cad/SG90 - Micro Servo 9g - Tower Pro.4.SLDPRT
cad/SG90 - Micro Servo 9g - Tower Pro.5.SLDPRT
cad/SG90 - Micro Servo 9g - Tower Pro.6.SLDPRT
cad/Tattu R-Line V4.0 1300mAh 130C 6S.SLDPRT
cad/Tattu R-Line V4.0 1300mAh 130C 6S.step
cad/Telemetry.SLDPRT
cad/Top Plate v2.SLDPRT
cad/battery strap.SLDPRT
cad/damper.SLDPRT
cad/lg base.SLDPRT
cad/lg damper.SLDPRT
cad/lg mount base.SLDPRT
cad/lg mount.SLDPRT
cad/lg vtube.SLDPRT
cad/payload box outline.SLDDRW
cad/payload box v1.SLDPRT
cad/payload r1.SLDPRT
cad/payload top.SLDPRT
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

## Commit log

2026-04-06 Add Zeus hexacopter CAD files — SolidWorks parts, assemblies, and render materials
    [Antenna 1.SLDPRT, Antenna 2.SLDPRT, Arm Tube.SLDPRT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]
2026-04-06 expand README with full design analysis, mechanism, and weight/BoM tables
2026-04-06 remove carbon fiber and rotorcraft badges

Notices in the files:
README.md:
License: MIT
